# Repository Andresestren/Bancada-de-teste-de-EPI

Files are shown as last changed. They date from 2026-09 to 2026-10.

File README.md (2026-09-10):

# Bancada automatiza para determinação de força do arco de protetores auditivos tipo concha

**Bancada automatiza o ensaio de força do arco de protetores auditivos, definido pela norma BS EN 13819-1. A concha do protetor é apoiada sobre um prato montado em uma célula de carga, e um motor de passo faz o deslocamento da concha do prato. A leitura da força é registrada automaticamente 120 segundos após a liberação, enquanto um sensor acompanha a temperatura e a umidade exigidas pela norma. O ensaio é operado pelo computador ou pelos comandos da própria bancada.

Essa força é o que mantém as conchas pressionadas contra a cabeça: se for baixa demais, a vedação falha e o protetor deixa de atenuar o ruído; se for alta demais, o usuário sente desconforto e tende a retirar o equipamento antes do fim da jornada. Medi-la é, portanto, parte da verificação de que o protetor realmente cumpre a função de proteger a audição do trabalhador.**

O desenvolvimento foi divido em quatro etapas:

- [Etapa 1](./etapa_1/README.md) (10/09/2026): Esboço da estrutura, diagrama de hardware de comunicação, descrição da norma e especificação dos componentes.
- [Etapa 2](./etapa_2/README.md) (01/10/2026): Definição dos componentes, diagrama do firmware e software, estrutura 3d externa e esquemáticos do circuito.
- [Etapa 3](./etapa_3/README.md) (29/10/2026): Diagramas de bloco completos, testes dos componentes e projeto da PCI.
- [Etapa 4](./etapa_4/README.md) (10/12/2026): Implementação do software e firmware, finalização e testes do projeto e aplicação de ajustes.

## Requisitos

**(Adicionar aqui os requisitos de hardware e software.)**

Este projeto foi implementado com os seguintes módulos/softwares/hardwares:

- […]
- […]
- […]
- […]

## Visão geral

**(Adicionar aqui um diagrama de blocos e um parágrafo de explicação resumida de cada bloco.)**

## Protótipo

**(Adicionar aqui uma foto do protótipo com UM parágrafo de explicação.)**

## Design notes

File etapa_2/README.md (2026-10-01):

# Etapa 2

Com a arquitetura e os requisitos definidos na etapa anterior, esta etapa escolhe os componentes e detalha o projeto eletrônico. Para cada bloco foram levantadas alternativas comerciais e comparadas contra os requisitos da Etapa 1. Em seguida foram desenvolvidos os diagramas de estados do firmware e do software, os esquemáticos de comunicação e de alimentação, e o modelo 3D da estrutura de ensaio.

## Desenvolvimento

### Definição dos componentes

| Bloco | Alternativas | Escolhido |
| :--- | :--- | :--- |
| Microcontrolador | STM32F411 · RP2040 · ESP32-S3 | ESP32-S3-WROOM-1-N8 |
| Conversor A/D | HX711 · NAU7802 · ADS1232 | ADS1232IPW |
| Driver do motor | A4988 · DRV8825 · TMC2209 | TMC2209-LA |
| Monitor de energia | INA219 · INA228 · INA226 | INA226 (×2) |
| Sensor ambiental | DHT22 · SHT31 · BME280 | BME280 |
| Regulador 3,3 V | AMS1117 · TPS7A91 | TPS7A91 |
| Proteção 24 V | Fusível+TVS · LM5069 · TPS26630 | TPS26630RGER |
| Proteção 5 V | Polyfuse · TPS2553 · TPS25210 | TPS25210ARPWR |
| Proteção ESD USB | Discretos · PRTR5V0U2X · USBLC6 | USBLC6-2SC6 |
| LED indicador | RGB discreto · APA102 · WS2812D | WS2812D |

As quatro decisões de maior impacto no ensaio:

**Microcontrolador.** Os dois núcleos com FreeRTOS separam a malha de tempo crítico da comunicação: a cronometragem dos 120 s e os pulsos do motor não competem com a pilha USB.

**Conversor A/D.** O HX711 é mais barato, mas sua referência vem do regulador interno, o que dificulta a medição raciométrica. O NAU7802 usa I2C, e colocaria o sinal mais sensível no barramento compartilhado.

**Sensor ambiental.** Existe para verificar as condições que a norma exige (22 ± 5 °C e até 85 % de umidade). O BME280 atende a faixa com margem.

**Driver do motor.** Como a leitura acontece 120 s após a liberação da concha, trancos no movimento perturbariam a medida; a interpolação do TMC2209 suaviza partida e parada.

**Trade-offs assumidos.** O SHT31 é mais exato que o BME280 em umidade (±2 % contra ±3 %) e o PRTR5V0U2X tem capacitância menor que o USBLC6-2SC6. Ambos foram preteridos por custo e disponibilidade, já atendendo o requisito.

### Diagrama de estados do firmware e do software

O firmware atende um comando por vez a partir de OCIOSO, executa, responde ao computador e volta a esperar. Na partida ele verifica os periféricos antes de aceitar qualquer comando de ensaio.

Diagrama de estados do firmware

O software conduz o ensaio: prepara, repete o ciclo de medição e encerra exportando o arquivo. Dois estados vêm da norma, o ajuste de largura e altura da bancada, e o descanso de 4 h antes de repetir o mesmo protetor em outra configuração.

Diagrama de estados do software

**Decisão de projeto:** quem carimba o instante da liberação (t0) é a placa, com o próprio relógio, devolvendo o valor na confirmação. O computador conta os 120 s a partir desse valor, o que tira o atraso variável do USB da conta, relevante porque a janela da norma é de apenas ±5 s.

### Esquemático do circuito de comunicação

Circuito de comunicação

Quatro dispositivos dividem o barramento I2C usando dois pinos: os dois monitores de energia, o sensor ambiental e o display. O driver do motor usa UART de fio único. O conversor A/D ficou fora do barramento compartilhado, com interface dedicada, por ser o sinal mais sensível a ruído.

### Esquemático do circuito de alimentação

Circuito de alimentação

As duas entradas são protegidas e monitoradas antes de alimentar o restante da placa. A malha de 3,3 V alimenta a parte digital e serve de excitação da célula de carga, o que justifica o requisito de ruído baixo definido na Etapa 1.

### Esquemático no KiCad

**ESP32-S3-WROOM-1 — Microcontrolador.** Lê os sensores, comanda o motor e troca dados com o computador.

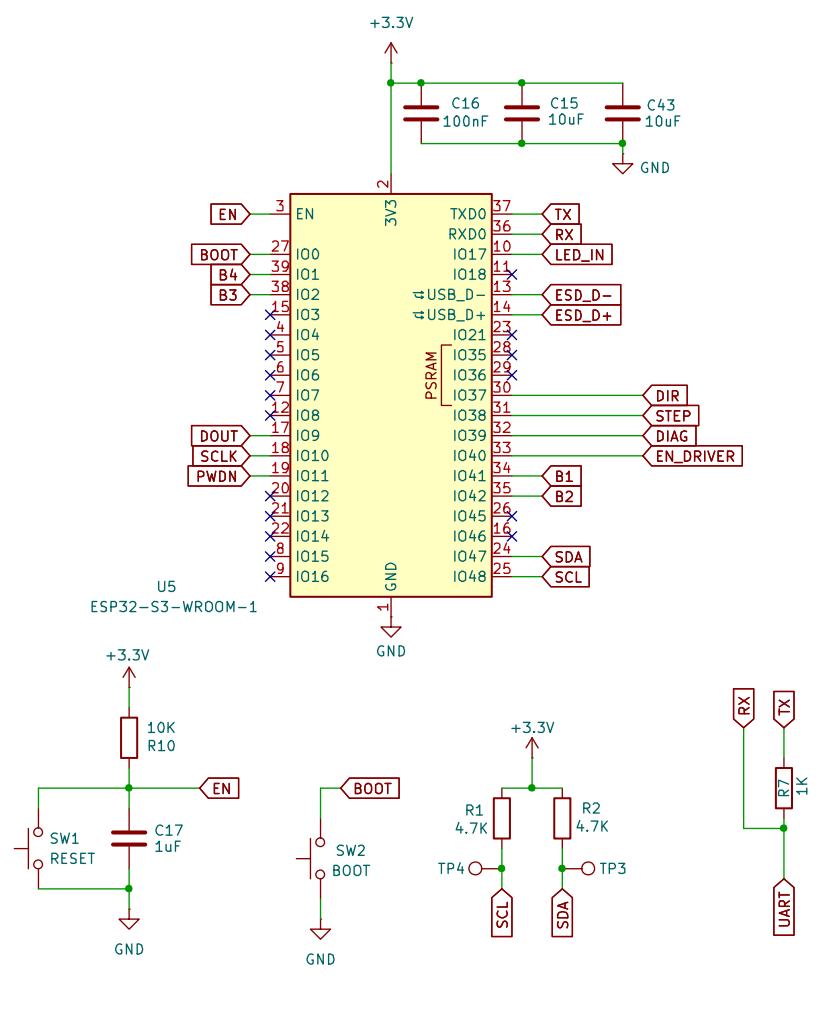
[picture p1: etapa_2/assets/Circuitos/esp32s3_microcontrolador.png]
Microcontrolador


**ADS1232IPW — ADC da célula de carga.** Amplifica e digitaliza o sinal de força.

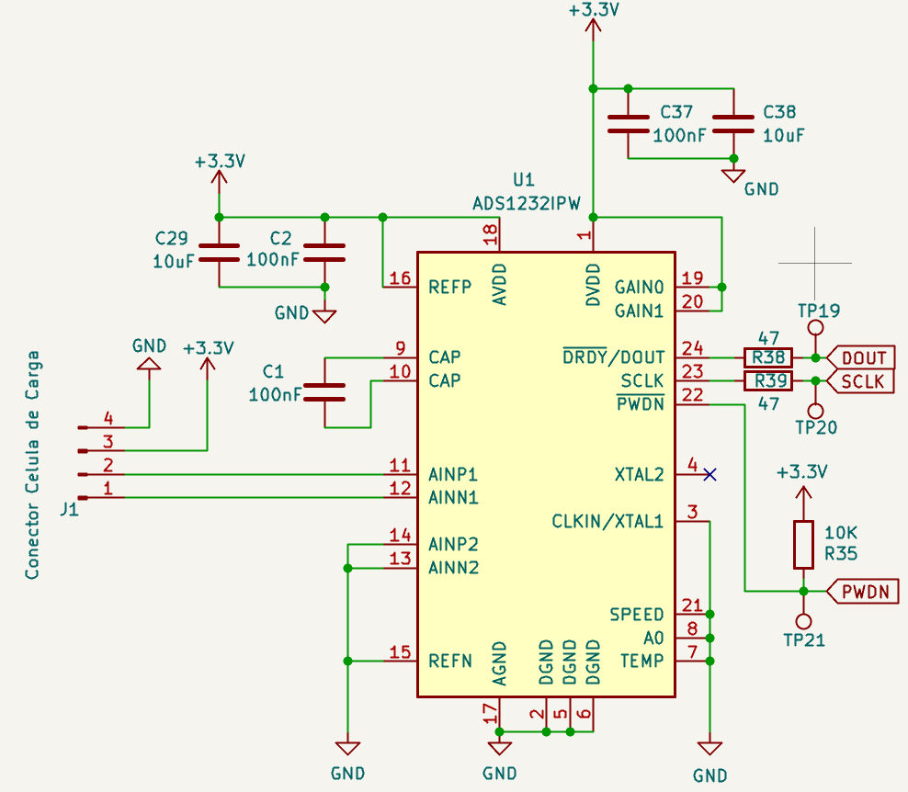
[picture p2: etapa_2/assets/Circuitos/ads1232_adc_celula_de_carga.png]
ADC da célula de carga


**TMC2209-LA — Driver do motor de passo.** Converte os comandos em corrente nas bobinas.

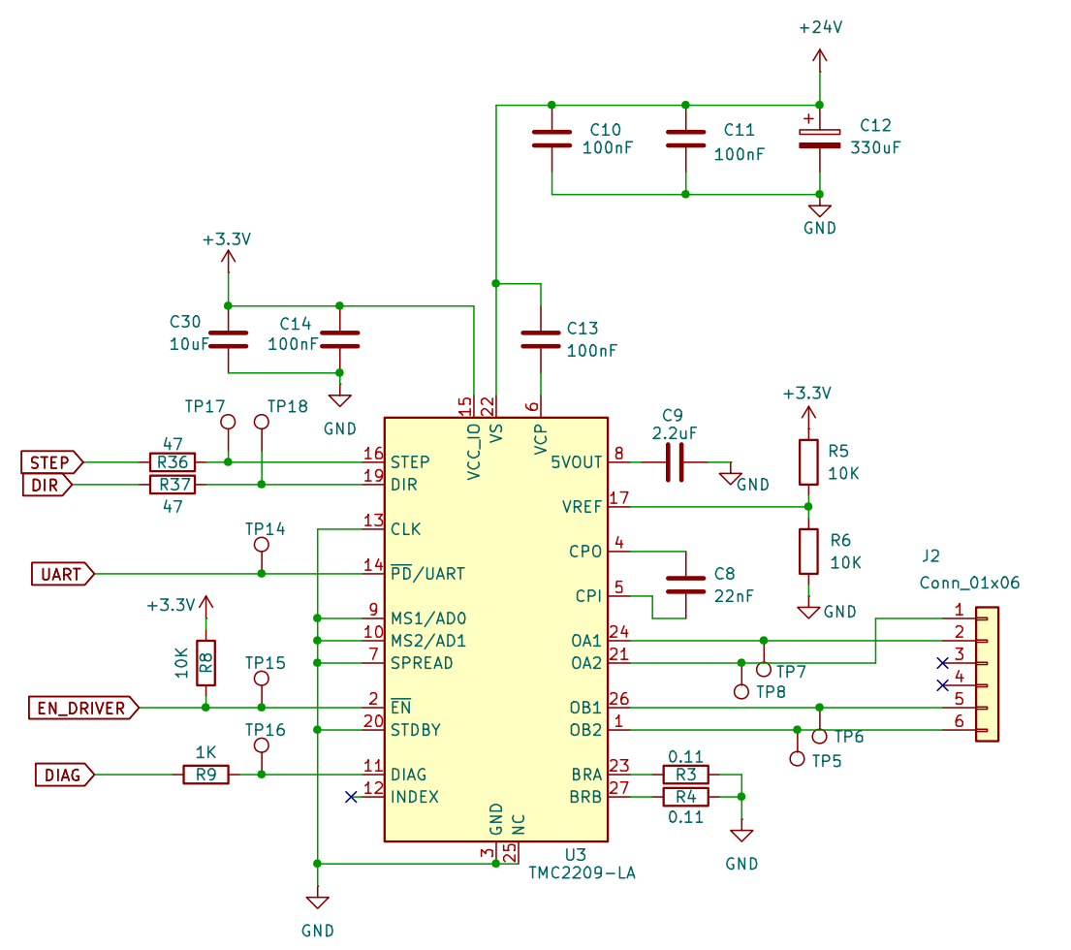
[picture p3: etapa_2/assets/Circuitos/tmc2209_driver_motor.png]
Driver do motor


**BME280 — Sensor ambiental.** Mede a temperatura e a umidade do ensaio.

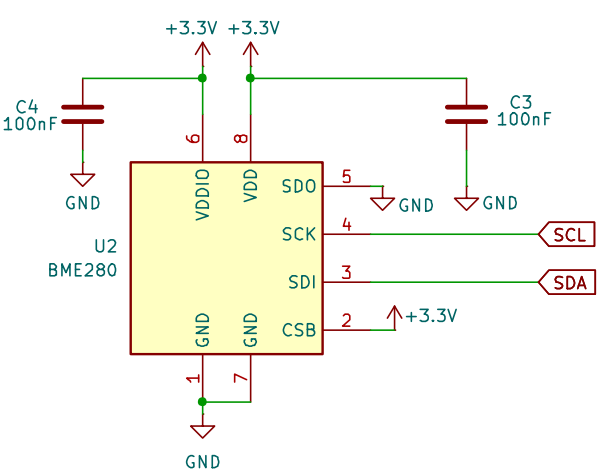
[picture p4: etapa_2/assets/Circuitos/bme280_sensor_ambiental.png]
Sensor ambiental


**INA226 — Monitor de 5 V.** Mede tensão, corrente e potência da linha de 5 V.

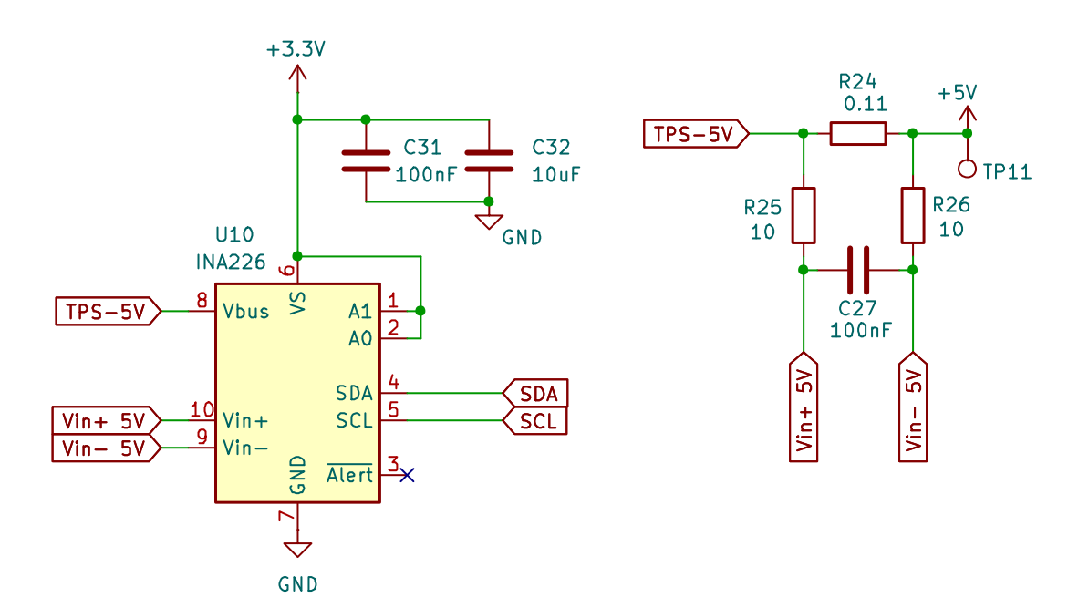
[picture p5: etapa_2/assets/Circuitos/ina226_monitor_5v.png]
Monitor de 5 V


**INA226 — Monitor de 24 V.** Mede tensão, corrente e potência da linha de 24 V.

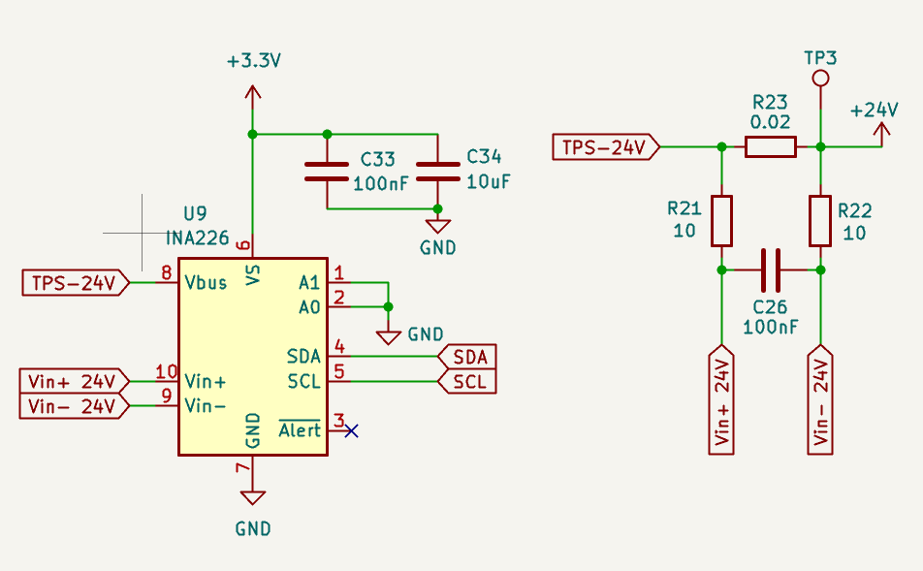
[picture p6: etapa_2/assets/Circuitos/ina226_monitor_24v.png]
Monitor de 24 V


**TPS7A91 — Regulador 3,3 V.** Gera a tensão da parte digital e da excitação da célula.

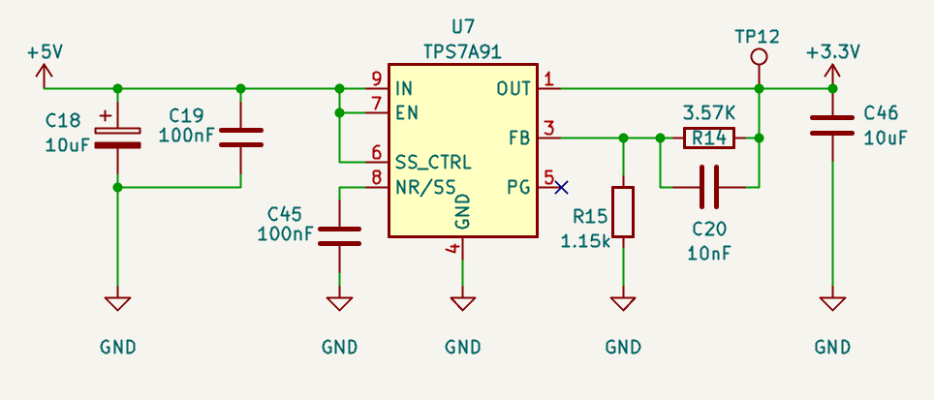
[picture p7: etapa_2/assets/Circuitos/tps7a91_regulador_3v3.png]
Regulador 3,3 V


**TPS25210ARPWR — eFuse 5 V.** Protege a entrada USB contra sobretensão e sobrecorrente.

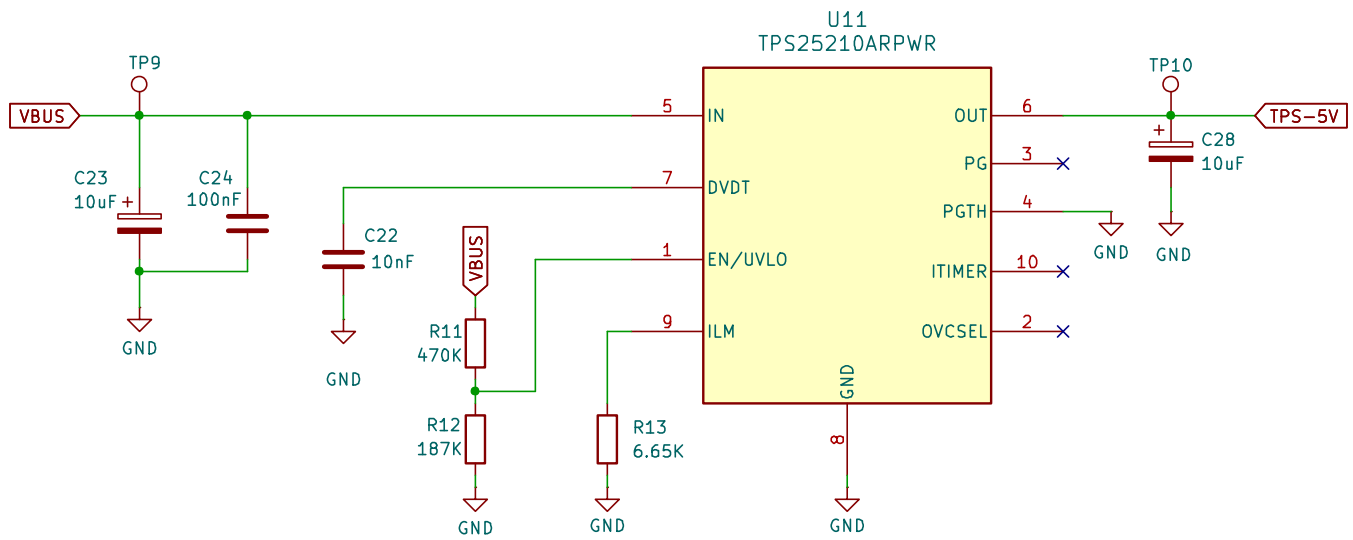
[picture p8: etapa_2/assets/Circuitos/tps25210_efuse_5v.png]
eFuse 5 V


**TPS26630RGE — eFuse 24 V.** Protege a entrada da fonte externa.

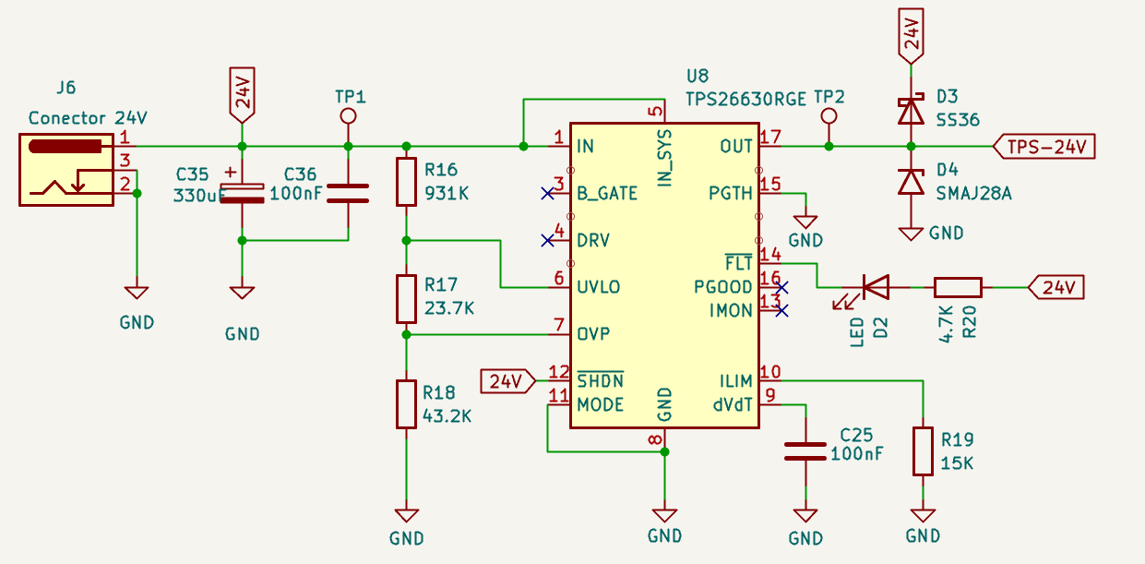
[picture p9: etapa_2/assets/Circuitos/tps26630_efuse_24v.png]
eFuse 24 V


**USBLC6-2SC6 — Proteção ESD.** Desvia as descargas eletrostáticas do cabo USB.

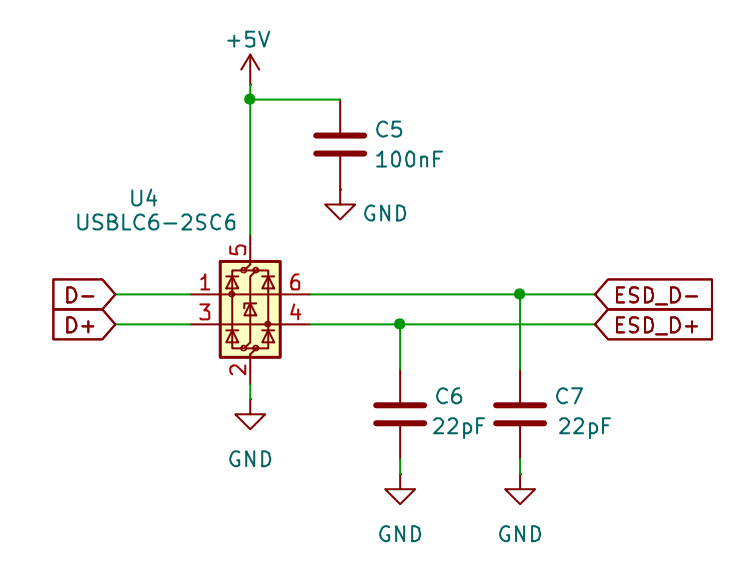
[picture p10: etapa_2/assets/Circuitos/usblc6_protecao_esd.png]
Proteção ESD


**WS2812D — LED indicador.** Sinaliza o estado do equipamento.

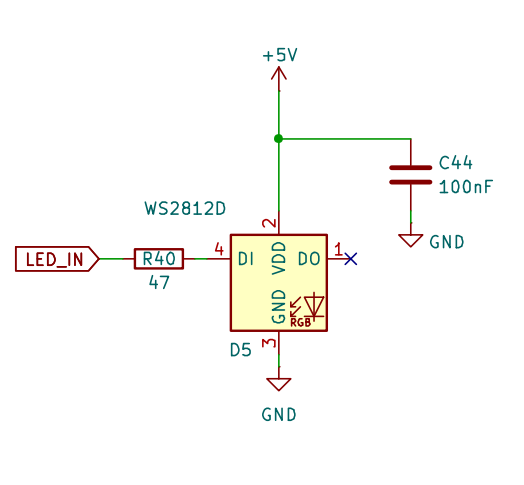
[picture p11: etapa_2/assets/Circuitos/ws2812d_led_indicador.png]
LED indicador


**Botões de ação.** Quatro entradas de comando do operador.

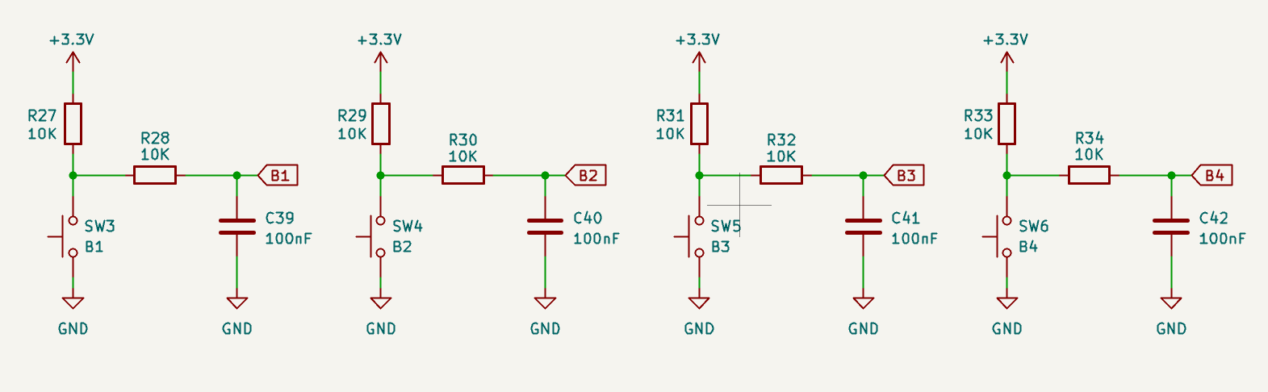
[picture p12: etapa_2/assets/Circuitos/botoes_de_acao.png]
Botões de ação


**Conector do display OLED.** Saída I2C para o display externo.

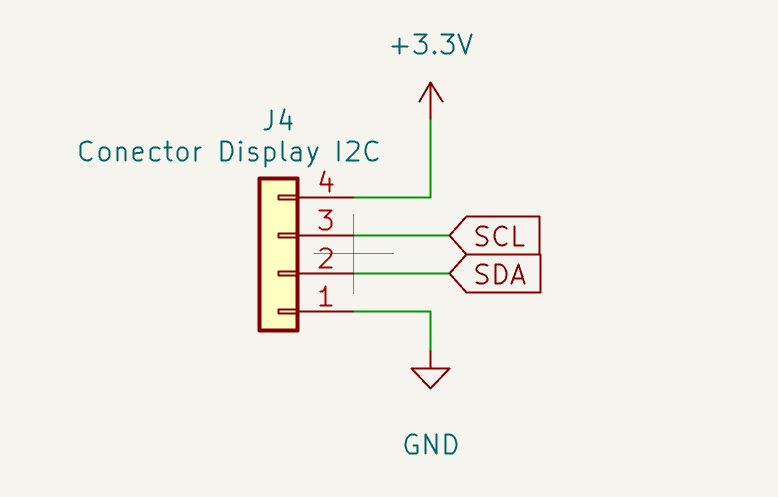
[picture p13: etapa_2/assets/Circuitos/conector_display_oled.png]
Conector do display


### Desenvolvimento 3D da estrutura de ensaio

[...]

## Referências

Norma **EN 13819-1:2020** via _BSI Standards Publication_: [EN 13819-1-2020 1.pdf](https://github.com/user-attachments/files/32043709/EN.13819-1-2020.1.pdf)

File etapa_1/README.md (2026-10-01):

# Etapa 1

Esta etapa define a arquitetura do equipamento inicial, antes da escolha dos componentes. Foram produzidos o diagrama de blocos de hardware e comunicação, a especificação funcional de cada bloco, o esboço da estrutura 3D e o levantamento da norma aplicável. Com a arquitetura fechada e os requisitos definidos, a seleção dos componentes passa a ser feita por critério técnico e, a partir do diagrama criado, serão desenvolvidos os esquemáticos do circuito e diagrama de estados na etapa seguinte.

## Desenvolvimento

### Diagrama de blocos de hardware e comunicação

Diagrama de blocos
*Figura 1 — Diagrama de blocos.*

**Alimentação**

| Bloco | Função |
| :--- | :--- |
| **Entrada de 24 V** | Fonte externa que alimenta a parte de potência do motor. |
| **Proteção da entrada de 24 V** | Alimenta o circuito em condição segura, cortando a energia em caso de falha. |
| **Monitor de energia (24 V)** | Mede tensão, corrente e potência dessa linha. |
| **Entrada USB (5 V)** | Alimenta a eletrônica de sinal e conecta o equipamento ao computador. |
| **Proteção da entrada de 5 V** | Mesma função, aplicada à linha de 5 V. |
| **Monitor de energia (5 V)** | Mede o consumo da linha de 5 V. |
| **Regulador de tensão** | Reduz os 5 V para os 3,3 V usados pela parte digital. |

**Controle e medição**

| Bloco | Função |
| :--- | :--- |
| **Microcontrolador** | Centro do sistema: lê os sensores, comanda o motor, atualiza o display e troca dados com o computador. |
| **Proteção ESD da USB** | Desvia as descargas eletrostáticas do cabo antes que alcancem o microcontrolador. |
| **Entrada da célula de carga** | Recebe o sinal de peso do sensor externo. |
| **Conversor A/D** | Amplifica e digitaliza o sinal da célula de carga. |
| **Sensor de temperatura e umidade** | Mede as condições do ambiente de operação. |

**Acionamento e interface**

| Bloco | Função |
| :--- | :--- |
| **Driver do motor de passo** | Converte os comandos do microcontrolador em corrente nas bobinas do motor. |
| **Saída para o motor** | Conexão do motor de passo ao equipamento. |
| **Botões de ação (4)** | Entrada dos comandos do operador. |
| **LED indicador** | Sinaliza o estado de funcionamento. |
| **Saída para o display** | Apresenta as informações ao operador. |

### Especificação dos componentes de hardware

Os componentes ainda não foram definidos, esta seção estabelece o que cada bloco precisa atender. O sistema é alimentado por 24 V (potência do motor) e por 5 V da porta USB, que é também o canal de comunicação com o software de PC que opera o equipamento. 

Toda a parte digital opera em 3,3 V. A comunicação entre os blocos será digital, em 3,3 V, com preferência por periféricos que compartilhem o mesmo barramento para economizar pinos. As interfaces serão definidas junto com a escolha dos componentes.

| Bloco | O que precisa atender |
| :--- | :--- |
| **Proteção das entradas (2)** | Desligar por subtensão ou sobretensão, limitar a corrente, partida suave e sinalizar falha. A de 24 V suporta corrente maior; a de 5 V respeita o limite de uma porta USB. |
| **Regulador 5 V → 3,3 V** | Corrente para toda a parte digital e baixo ruído, pois a mesma tensão alimenta o circuito de pesagem. |
| **Monitores de energia (2)** | Medir tensão, corrente e potência das linhas de 5 V e 24 V. |
| **Microcontrolador** | Pinos para todos os blocos; sinais em 3,3 V; comunicação USB para gravação e para o software do computador; pulsos com temporização precisa. |
| **Conversor A/D** | Sinal diferencial de poucos milivolts: amplificar, converter com alta resolução, filtrar a interferência da rede e manter a leitura estável. |
| **Sensor de temperatura e umidade** | Saída digital já calibrada, ±1 °C e ±3 % de umidade, alimentação em 3,3 V. |
| **Driver do motor de passo** | Motor bipolar NEMA 17 em 24 V; passo, direção e habilitação; micropassos; desligado por padrão ao energizar; proteção térmica e de sobrecorrente. |
| **Botões (4)** | Comandos do operador e durabilidade para uso frequente. |
| **LED indicador** | Estado do equipamento em mais de uma cor, com o mínimo de pinos. |
| **Conector do display** | Display externo, ligado por cabo; conector polarizado e com travamento. |
| **Proteção da porta USB** | Desviar as descargas eletrostáticas sem degradar o sinal. |
| **Conectores externos** | Folga de corrente no 24 V e no motor; boa fixação do USB; conectores distintos entre si. |

### Esboço da estrutura 3D
 
A estrutura tem dois anteparos verticais e mede cerca de 180 × 209 × 107 mm (Figura 3). O motor gira o fuso roscado, que desloca a régua de acoplamento; os eixos passantes atravessam o anteparo e levam o movimento à régua de deslocamento, que coloca e libera a concha do protetor sobre o prato. O prato é sustentado pela célula de carga, onde a força do arco é medida (Figura 4).
 
Peças da estrutura
*Figura 2 — Peças da estrutura.*
 
| Item | Peça | Função |
| :--- | :--- | :--- |
| 1 | Anteparo traseiro | Sustenta o motor e o fuso. |
| 2 | Régua de acoplamento | Abriga a castanha do fuso e recebe o movimento linear. |
| 3 | Régua de deslocamento | Coloca e libera a concha sobre o prato. |
| 4 | Prato balança | Superfície de apoio da concha. |
| 5 | Eixo passante | Liga as duas réguas através do anteparo. |
| 6 | Célula de carga | Sustenta o prato e converte a força em sinal elétrico. |
| 7 | Anteparo frontal | Sustenta a célula de carga e o prato. |
| 8 | Fuso roscado | Transforma o giro em deslocamento linear. |
| 9 | Motor de passo | Aciona o fuso. |

Dimensões

*Figura 3 — Dimensões principais.*

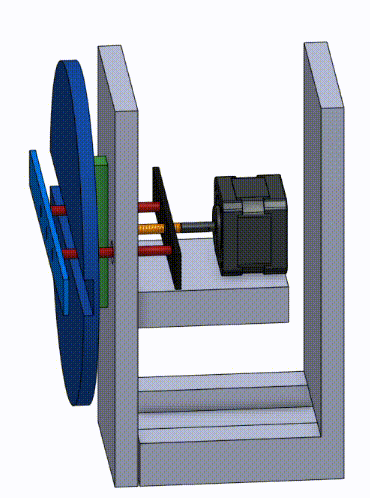
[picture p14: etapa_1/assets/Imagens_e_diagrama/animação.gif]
Animação


*Figura 4 — Movimento de colocação e liberação.*

### Descrição da Norma

**BS EN 13819-1:2020: Ensaios Físicos de Protetores Auditivos**

Esta norma europeia especifica os métodos padronizados de ensaios físicos para protetores auditivos, como abafadores e plugues.

#### Requisitos Mecânicos

* **Dispositivo de Teste ([Seção 4.2.2.1](https://github.com/user-attachments/files/32043709/EN.13819-1-2020.1.pdf)):** A norma exige a utilização de uma estrutura com um transdutor de força para medir eletronicamente a carga exercida pelos abafadores.

* **Controle Dimensional ([Seção 4.4.3](https://github.com/user-attachments/files/32043709/EN.13819-1-2020.1.pdf)):** O sistema deve garantir que as duas placas de suporte se mantenham estritamente paralelas durante o teste. A separação das superfícies externas dessas placas deve ser ajustável para corresponder a larguras de teste padronizadas, sendo 135 mm _(Tamanho P)_, 145 mm _(Tamanho M)_ e 150 mm _(Tamanho G)_.
* **Alinhamento do Centro de Medição ([Seções 4.4.2.2 e 4.4.3.2.3](https://github.com/user-attachments/files/32043709/EN.13819-1-2020.1.pdf)):** A estrutura mecânica deve garantir que as aberturas das almofadas sejam posicionadas de modo que seus centros coincidam exatamente com o eixo horizontal que passa pelo centro do transdutor de força.
* **Ajuste de Altura ([Tabela 4 e Seção 4.4.3.2.3](https://github.com/user-attachments/files/32043709/EN.13819-1-2020.1.pdf)):** A mecânica da bancada deve permitir o ajuste da altura do suporte do arco _(distância vertical em relação ao centro das conchas)_. Para abafadores usados sobre a cabeça, as alturas normatizadas são 122 mm _(Tamanho P)_, 130 mm _(Tamanho M)_ e 135 mm _(Tamanho G)_.

#### Temporização e Monitoramento

* **Janela de Leitura Crítica ([Seção 4.4.3.2.4](https://github.com/user-attachments/files/32043709/EN.13819-1-2020.1.pdf)):** A norma determina que a medição oficial da força do arco deve ser lida no indicador exata e automaticamente em 120 ± 5 segundos após a liberação do protetor no suporte.
* **Condições de Contorno ([Seção 4.1.2](https://github.com/user-attachments/files/32043709/EN.13819-1-2020.1.pdf)):** A norma estipula atmosferas específicas de condicionamento e teste, exigindo uma temperatura de 22 ± 5 °C e uma umidade relativa não superior a 85%.
* **Período de Descanso entre Ensaios ([Seção 4.4.3.2.5](https://github.com/user-attachments/files/32043709/EN.13819-1-2020.1.pdf)):** Quando um mesmo protetor auditivo for submetido a testes sequenciais em diferentes larguras e alturas, o sistema deve respeitar um período mínimo de descanso de 4 horas antes da próxima medição.

## Referências

Norma **EN 13819-1-2020** 1 via _BSI Standards Publication_: [EN 13819-1-2020 1.pdf](https://github.com/user-attachments/files/32043709/EN.13819-1-2020.1.pdf)

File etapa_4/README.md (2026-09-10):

# Etapa 4

Esta etapa tem como objetivos:
- Desenvolver a comunicação entre CIs e driver/motor;
- Implementação do software e firmware;
- Teste e ajustes necessários na estrutura e software.

**(Parágrafo com visão geral da etapa.)** [...]

## Desenvolvimento

**(Apresentar o desenvolvimento da etapa.)** [...]

## Testes

**(Descrição dos testes/validações realizadas.)** [...]

## Referências (links/datasheets/livros)

 [...]

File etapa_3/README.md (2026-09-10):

# Etapa 3

Esta etapa tem como objetivos:
- Montar os diagramas de blocos completos da comunicação e alimentação;
- Realizar os testes do motor e célula de carga;
- Finalizar o projeta da PCI.

**(Parágrafo com visão geral da etapa.)** [...]

## Desenvolvimento

**(Apresentar o desenvolvimento da etapa.)** [...]

## Testes

**(Descrição dos testes/validações realizadas.)** [...]

## Referências (links/datasheets/livros)

 [...]

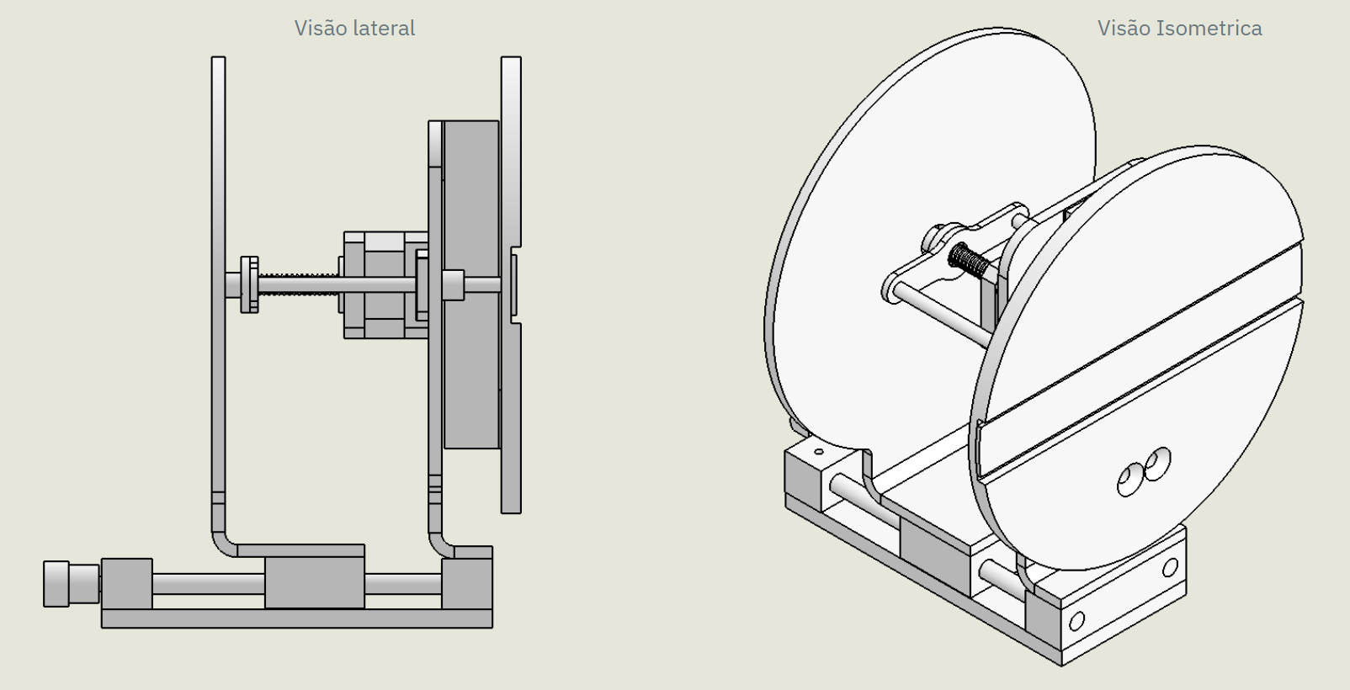
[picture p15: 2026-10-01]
etapa_2/assets/Imagens_e_diagrama/estrutura_vistas.png

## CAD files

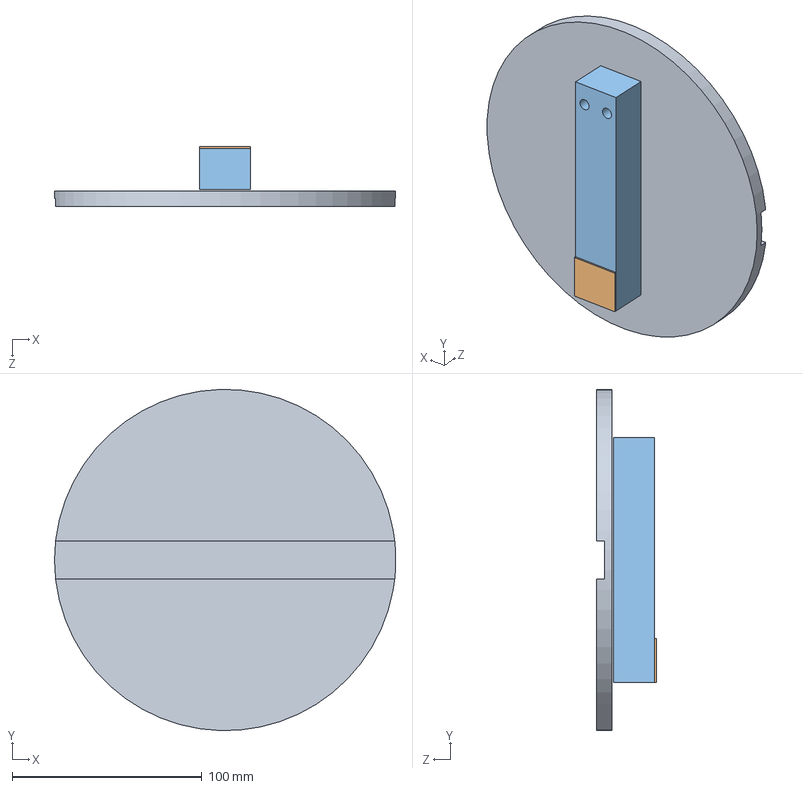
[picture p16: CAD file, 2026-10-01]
etapa_2/assets/modelos_3d/Prato + celula de carga montagem.SLDASM
179.8 x 179.9 x 31.5 mm
Celula de Carga
Espaçador 2
Prato de força

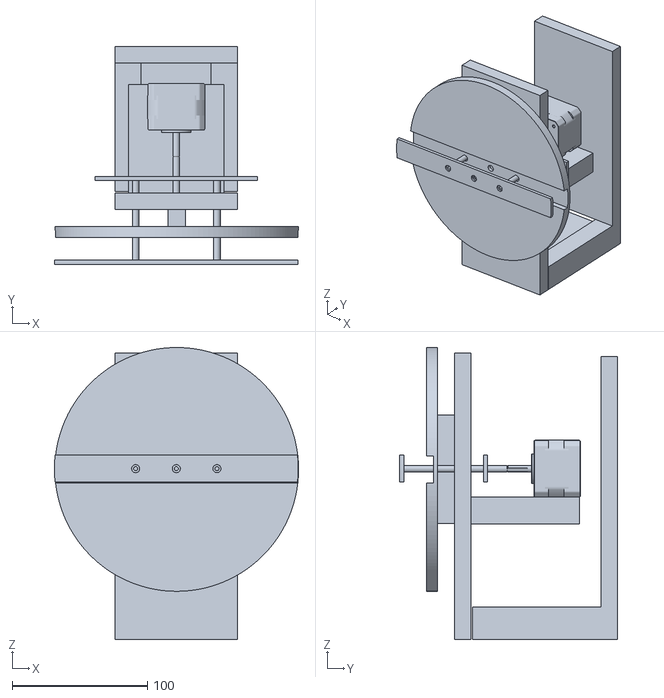
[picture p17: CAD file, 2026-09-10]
etapa_1/assets/modelos_3d/Visualização.stl
180.3 x 160.7 x 215.6

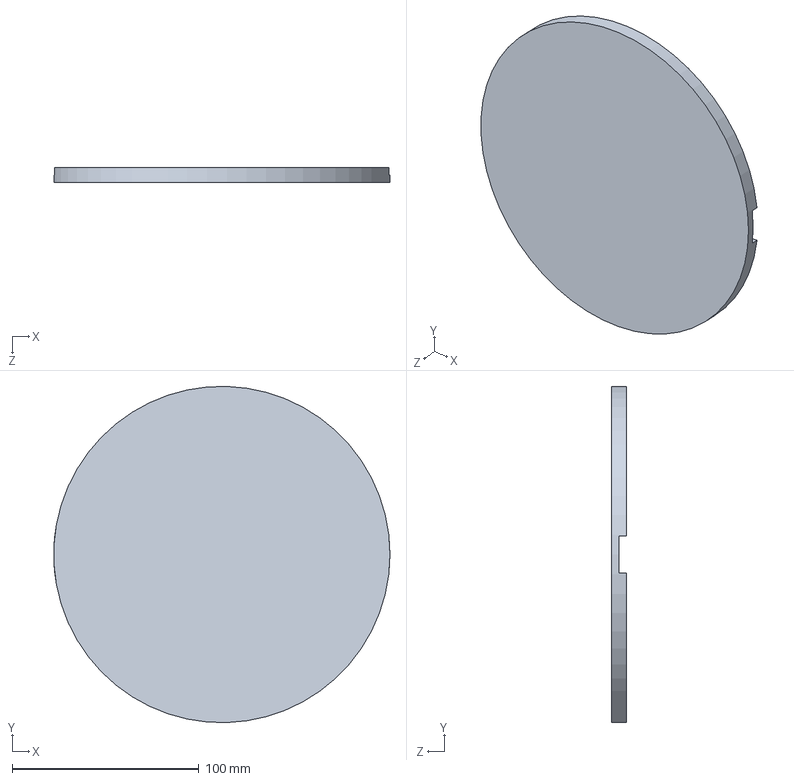
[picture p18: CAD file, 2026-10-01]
etapa_2/assets/modelos_3d/Prato de força.SLDPRT
179.8 x 179.9 x 8.00 mm

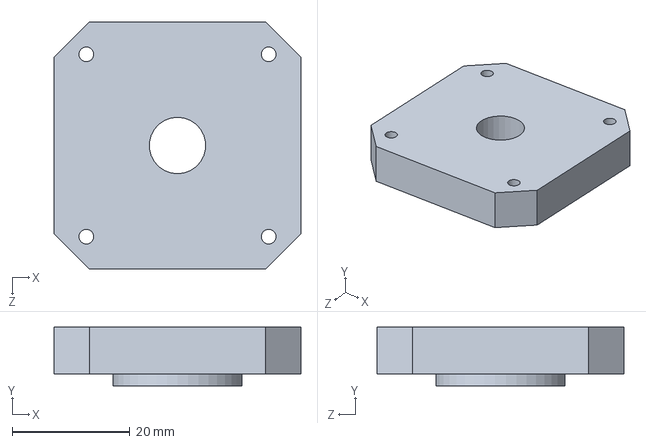
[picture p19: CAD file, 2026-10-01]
etapa_2/assets/modelos_3d/Tampa frontal.SLDPRT
42.0 x 10.0 x 42.0 mm

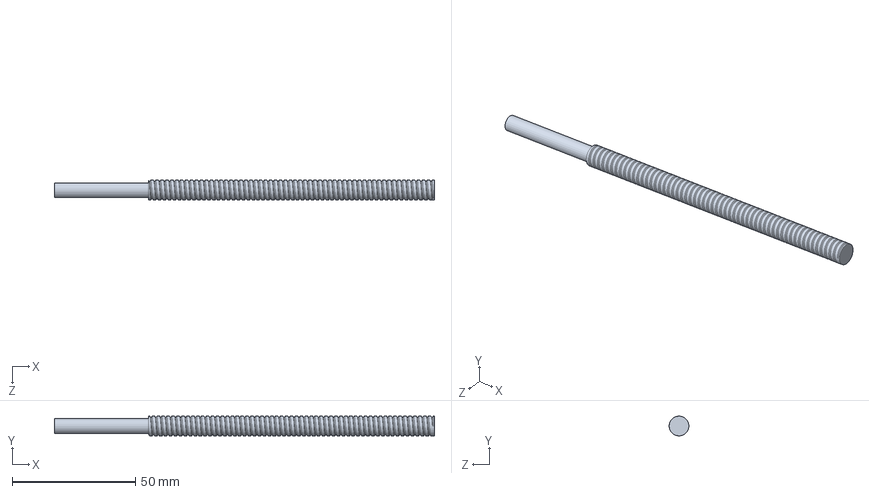
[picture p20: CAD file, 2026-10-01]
etapa_2/assets/modelos_3d/Barra roscada.SLDPRT
154.0 x 8.00 x 8.00 mm

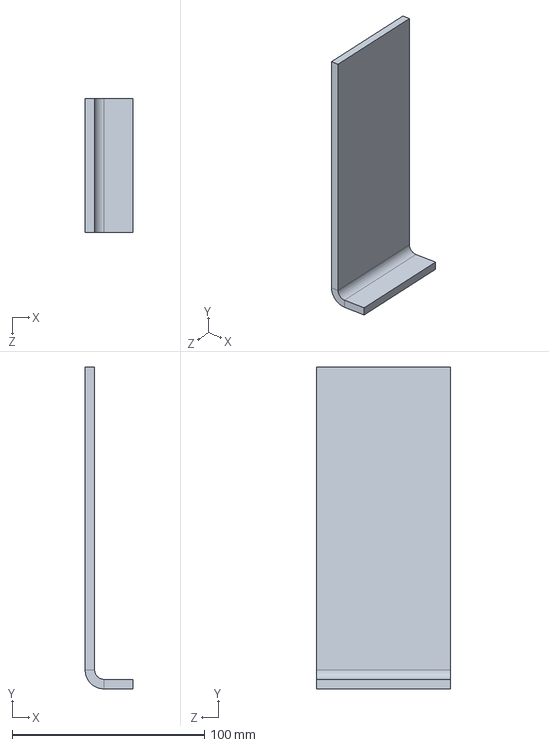
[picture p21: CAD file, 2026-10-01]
etapa_2/assets/modelos_3d/Suporte L celula de carga.SLDPRT
25.0 x 167.6 x 70.0 mm

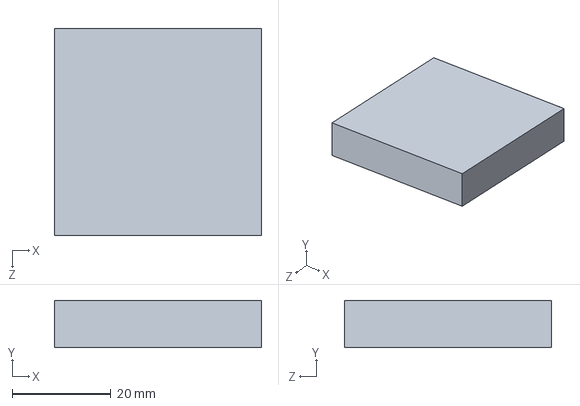
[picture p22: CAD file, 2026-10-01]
etapa_2/assets/modelos_3d/Tampa traseira.SLDPRT
42.0 x 9.55 x 42.0 mm

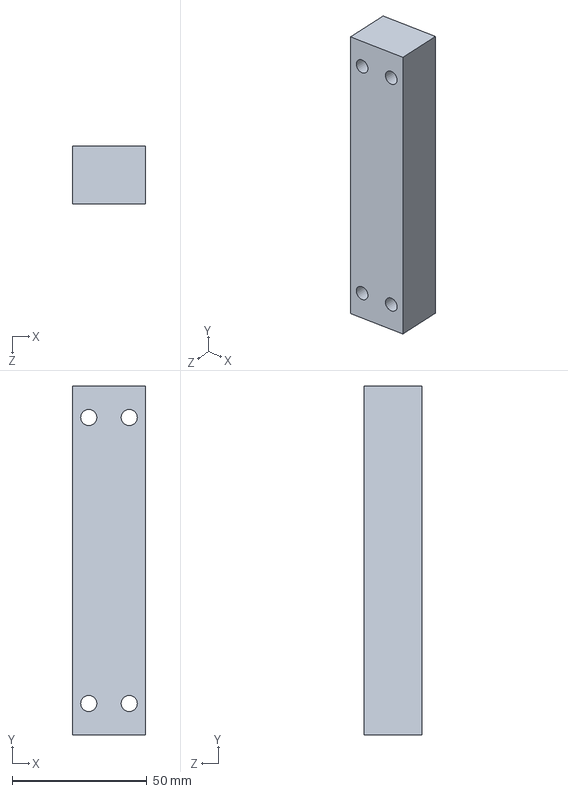
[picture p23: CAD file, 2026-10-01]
etapa_2/assets/modelos_3d/Celula de Carga.SLDPRT
26.9 x 129.3 x 21.5 mm

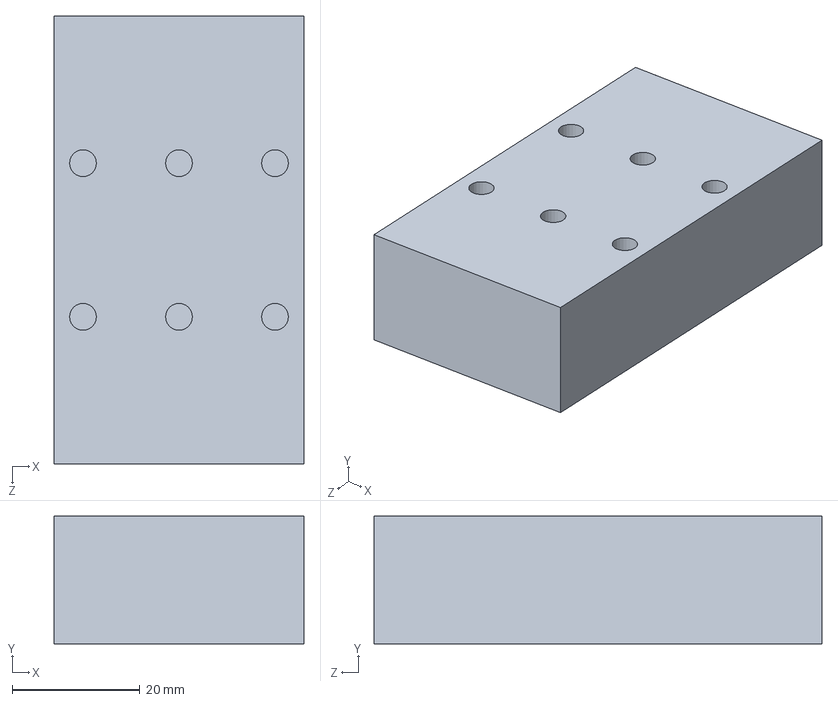
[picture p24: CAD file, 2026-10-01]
etapa_2/assets/modelos_3d/Base deslizante.SLDPRT
39.0 x 20.0 x 70.0 mm

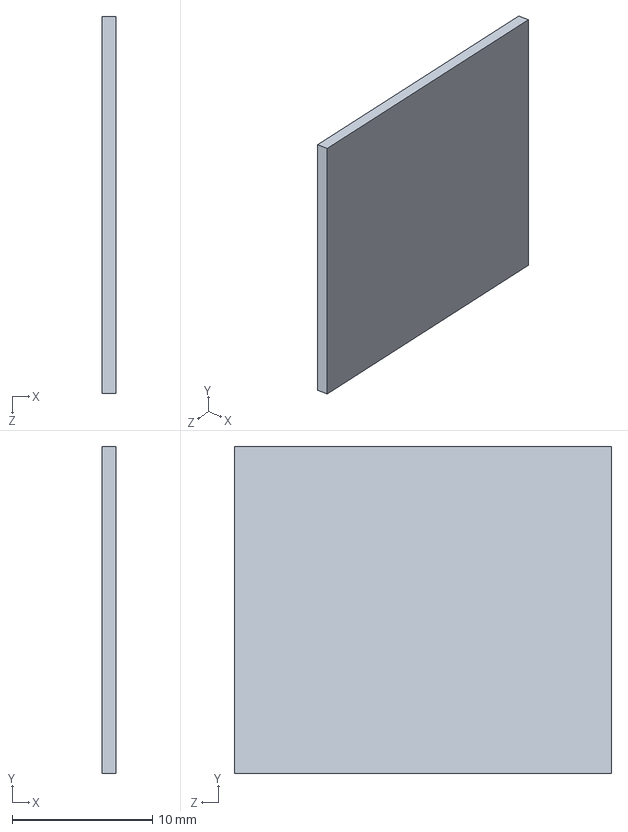
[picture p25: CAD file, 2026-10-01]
etapa_2/assets/modelos_3d/Espaçador 2.SLDPRT
1.00 x 23.4 x 26.9 mm

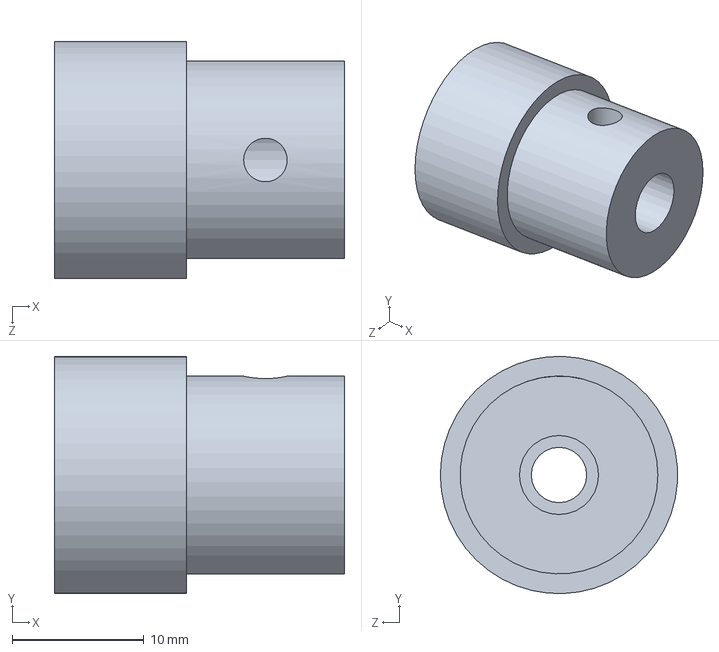
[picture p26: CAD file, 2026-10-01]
etapa_2/assets/modelos_3d/Volante de fuso.SLDPRT
22.0 x 18.0 x 18.0 mm

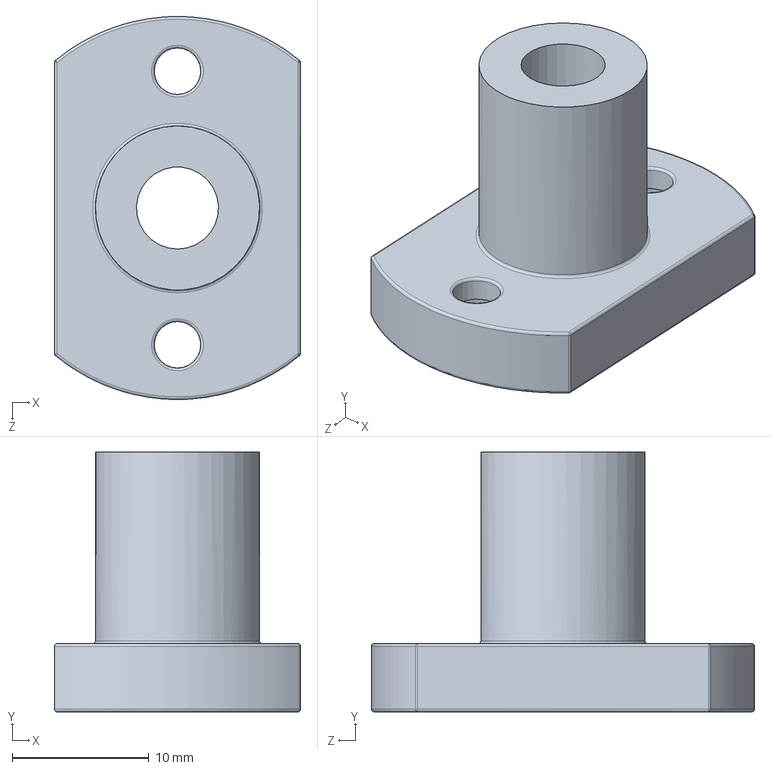
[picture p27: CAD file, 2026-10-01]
etapa_2/assets/modelos_3d/Rolamento linear.SLDPRT
18.0 x 19.0 x 28.0 mm

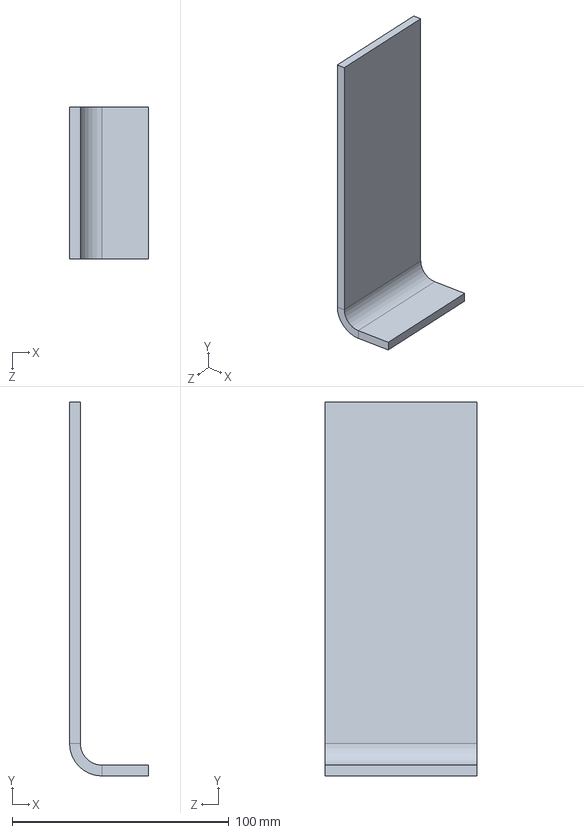
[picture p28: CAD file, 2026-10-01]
etapa_2/assets/modelos_3d/Suporte L deslisante Segunda opção.SLDPRT
36.5 x 172.6 x 70.0 mm

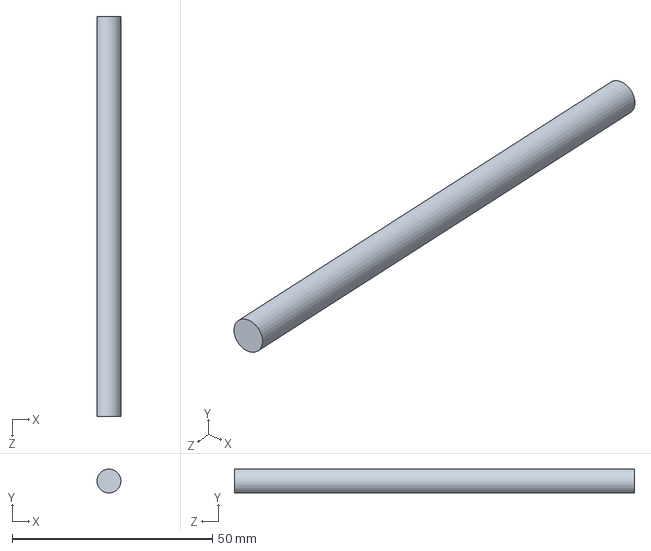
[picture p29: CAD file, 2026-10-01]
etapa_2/assets/modelos_3d/Eixo de deslocamento 2.SLDPRT
5.98 x 5.99 x 100.0 mm

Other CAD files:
etapa_2/assets/modelos_3d/Montagem de regua de acoplamento e deslocamento.SLDASM
etapa_2/assets/modelos_3d/Mesa linear montagem.SLDASM
etapa_2/assets/modelos_3d/Montagem Estrutura DEFA.SLDASM
etapa_2/assets/modelos_3d/Nema17.SLDASM
etapa_2/assets/modelos_3d/Base mesa linear.SLDPRT
etapa_2/assets/modelos_3d/Castanha para fuso.SLDPRT
etapa_2/assets/modelos_3d/Eixo1.SLDPRT
etapa_2/assets/modelos_3d/Eixo2.SLDPRT
etapa_2/assets/modelos_3d/Espaçador1.SLDPRT
etapa_2/assets/modelos_3d/Estator.SLDPRT
etapa_2/assets/modelos_3d/Fuso motor.SLDPRT
etapa_2/assets/modelos_3d/Regua de acoplamento.SLDPRT
etapa_2/assets/modelos_3d/Regua de deslocamento.SLDPRT
etapa_2/assets/modelos_3d/Suporte L deslizante.SLDPRT
etapa_2/assets/modelos_3d/Suporte de eixo 1.SLDPRT
etapa_2/assets/modelos_3d/Suporte de eixo 2.SLDPRT

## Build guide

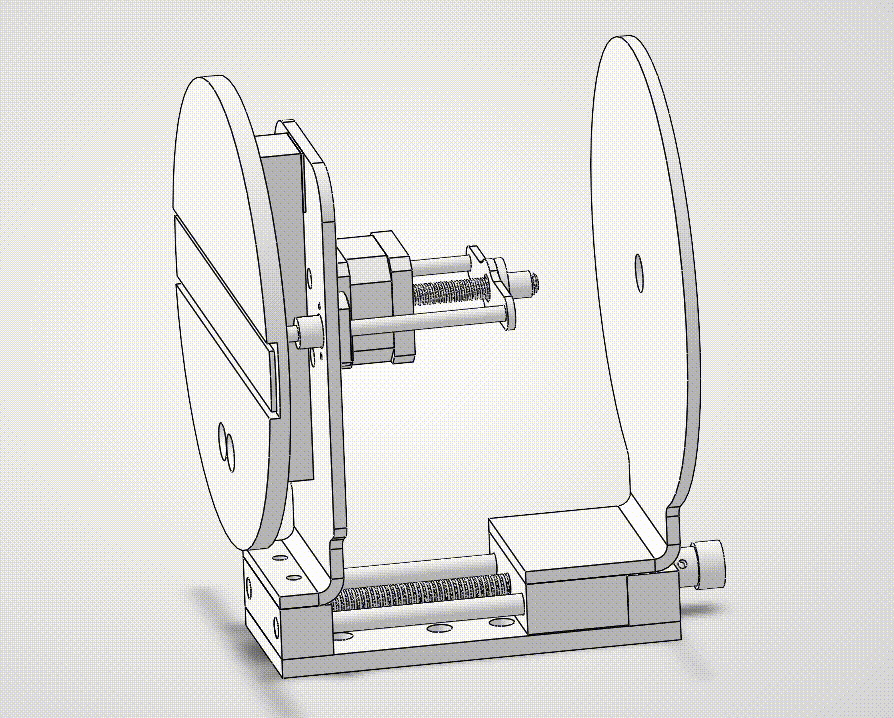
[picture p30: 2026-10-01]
etapa_2/assets/Imagens_e_diagrama/Montagem-Estrutura-DEFA-gif.gif

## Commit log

2026-09-10 alteração de pasta
2026-09-10 correção dimensões, animação e BOM
2026-09-10 ARQUIVO 3D
    [Montagem Sistema V04 - motor.stl]
2026-09-10 adição montagem 3d
    [Visualização.stl]
2026-10-01 Adicionados diagramas de comunicação/alimentação
2026-10-01 Atualização Readme e upload 3d
    [Barra roscada.SLDPRT, Base deslizante.SLDPRT, Base mesa linear.SLDPRT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]
2026-11-09 add case e teste
